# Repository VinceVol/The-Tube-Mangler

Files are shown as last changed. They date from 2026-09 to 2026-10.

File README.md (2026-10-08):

# The-Tube-Mangler
Looking to create a CNC plasma tube notcher &amp; pen plotter to work with 1/2" -> 2" tubing. 

## Active Todos!
- [x] Change the rack mounting to holes rather than slots
- [x] Design for the [rugged limit switches](https://www.amazon.com/Baomain-TZ-3111-Plunger-Momentary-Waterproof/dp/B01HKSDVAK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) used on Jasper the CNC
- [x] Add pulley clearance for axial drive
- [ ] Add encoder mounting location for axial position -- [E4T-1000-197-D-D-M-2 encoder](https://www.digikey.com/en/products/detail/us-digital/E4T-1000-197-D-D-M-2/27558059)
- [ ] Check that all mating holes still line up after several iterations
- [x] Animate the full rotation of the rotary axis to preview collisions
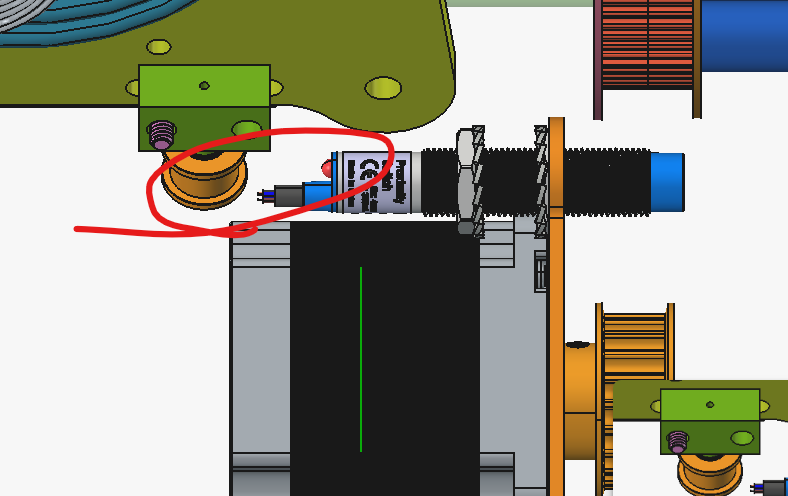
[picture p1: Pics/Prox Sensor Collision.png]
axial tensioning idler collision
	- [x] Move the rotational homing prox sensor to avoid  or find stubby prox sensor
- [ ] Design for cable chains and wire routing
- [ ] Design for physical panel location
- [ ] Draw up schematic using linuxCNC Mesa [7I76EU](https://store.mesanet.com/index.php?route=product/product&product_id=399&search=7I76EU) -- [datasheet](https://www.mesanet.com/pdf/parallel/7i76euman.pdf)

# Path to success
## Step 1 
Mechanical design surrounding the pen plotting/ clamping/ rotating and movement of the tubing

### Axial Roller Drive Math
Outside of literally just trying to fit everything into one small space, we've run into our first issue that requires some brain cells.

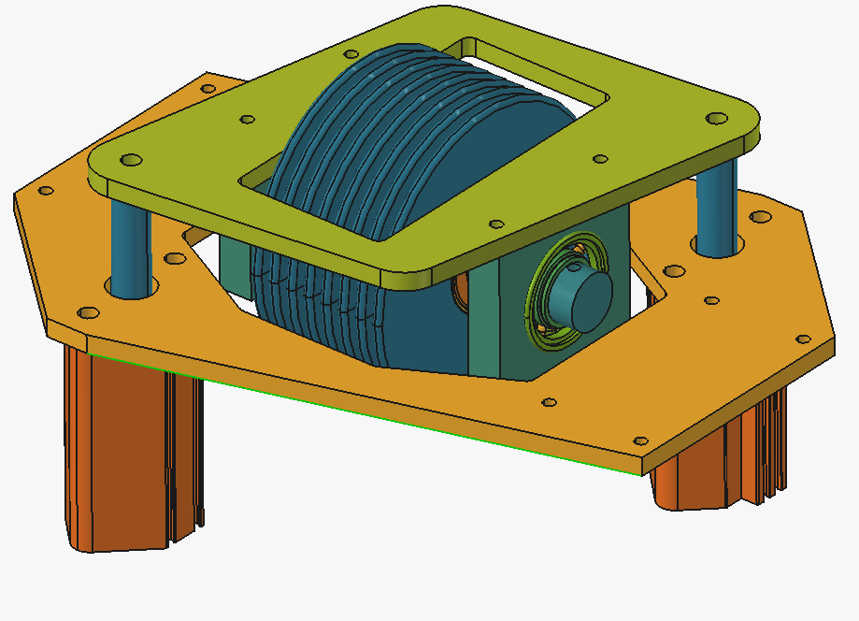
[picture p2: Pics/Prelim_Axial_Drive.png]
**Fig 1.1:** *Axial Drive Preliminary*


The [non slip roller](https://www.mcmaster.com/2494K18/) in the center is has a OD = 4" and the two [air cylinders](https://www.mcmaster.com/62245K166/) have a 1" bore.
At 90 psi we are putting *2 x 90 lbs/in^2 x pi(0.5)^2 in^2 = **141.37** lbs* of force down on this roller. There are two main problems to solve here:

1. Will this "non slip" roller actually not slip at 141 lbs of downforce?
2. Will a stepper motor setup for direct drive stall without some kind of reduction to the non-slip roller?  

Answers:
1. AI says its fine and this feels like more of a "find out" scenario
2. *t = F x r, r = 0.0508m (2in), t = 3 Nm* (big boy stepper), with that we would get *F = 59N = 13lbf*. If we want to chuck up a full 20ft stick of 3"x3" 1/4" thick piece
of tubing at 176lbs, we'd have a hard time doing so with 13lbf. **We need a significant reduction** 

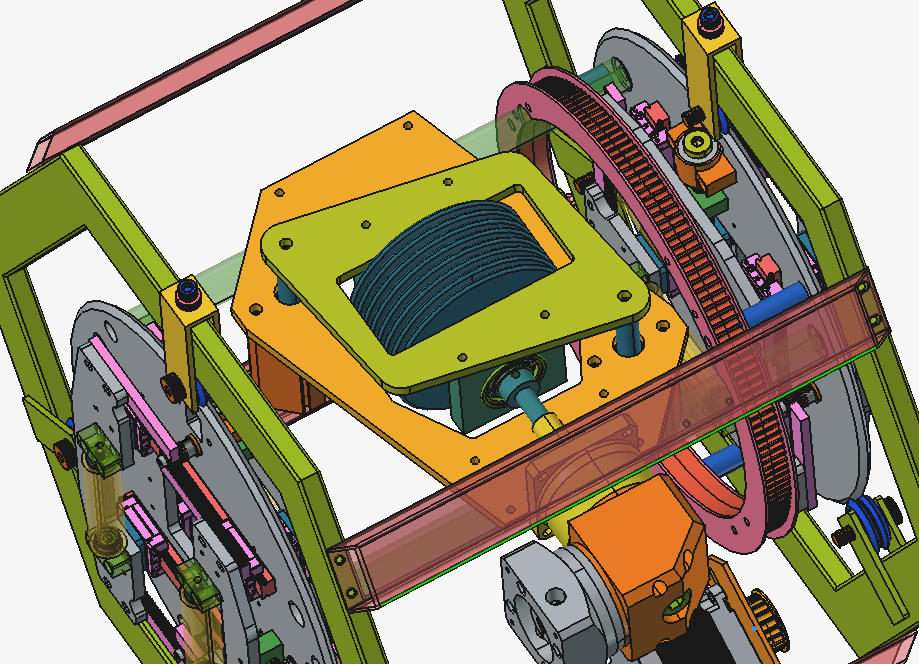
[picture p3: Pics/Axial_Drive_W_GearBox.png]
**Fig 1.2:** *10:1 Gearbox doesnt fit*


Right angle gearbox above was my first thought but it doesnt fit super well. If I downsize to a Nema 17 motor and use a straight 100:1 and using the same sized pulley
to connect the gear box to the roller I think the fit is just about right:

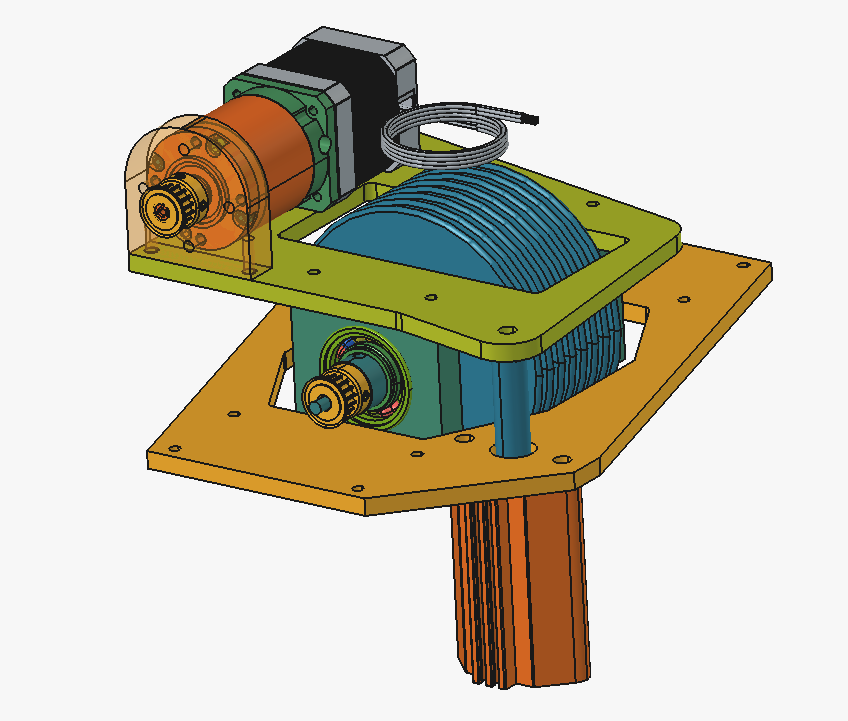
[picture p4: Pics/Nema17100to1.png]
**Fig 1.3:** *100:1 Gearbox w/ Nema 17*


## Step 2 
Addition of plasma cutter

## Step 3
Add the ability --software wise-- to cut square tube

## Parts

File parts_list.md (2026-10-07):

# Parts Lists

## Symmetrical Clamping Chuck

!\[Image of chuck](path)

|**Part Description**|**Part Name**|**Qnty**|**Price**|
|:-:|:-:|:-:|:-:|
|Carriage rep|6709K115|\~|\~|
|Linear Rail|[MGN12C\_150mm](https://ebay.io/m/mMSGYF)|8|20.40|
|Rack Rep|2485N241|\~|\~|
|Pinion Rep|2664N312|\~|\~|
|Pinion Shoulder Bolt|[92981A745](https://www.mcmaster.com/92981A745/)|\~|\~|
|Pinion Shoulder Bolt Bearing|[6659K113](https://www.mcmaster.com/6659K)|\~|\~|
|Pinion Shoulder Bolt Washer|[98689A113](https://www.mcmaster.com/98689A113/)|\~|\~|
|Drive Screw Thrust Bearing|6655K15|\~|\~|
|15 mm GT2/HTD|[7939K15](https://www.mcmaster.com/7939K15/)|\~|\~|

## Chuck Housing

!\[Image of housing](path)

|**Part Description**|**Part Name**|**Qnty**|**Price**|
|:-:|:-:|:-:|:-:|
|Track Bearings|[6321K51](https://ebay.io/m/LhClsj)|\~|\~|
|Track Shoulder Shim Washers|[90214A904](https://a.co/d/0chW9DGh)|\~|\~|
|Bellville Disc Spring|[9712K63](https://www.mcmaster.com/9712K63/)|\~|\~|
|Radial Stepper Motor|[Amazon Hight Torque](https://a.co/d/07xEF6Ci)|\~|\~|
|HTD 5 Belt 890mm|[7939K28](https://www.mcmaster.com/7939K28/)|\~|\~|
|Proximity Sensor|[LJ8A3-2-Z/BY](https://a.co/d/01RUSQrh)|1|22.99|

## Axial Drive

!\[Image of Axial Shit](path)

|**Part Description**|**Part Name**|**Qnty**|**Price**|
|:-:|:-:|:-:|:-:|
|Flanged Bearings|[1.375x0.75x7/8](https://ebay.io/m/fyqjXr)|\~|\~|
|276mm 6mm HTD Belt|[7939K15](https://www.mcmaster.com/7939K15/)|1|26.54|

## Torch \& Pen

!\[Image of that](path)

|**Part Description**|**Part Name**|**Qnty**|**Price**|
|:-:|:-:|:-:|:-:|
|Linear Rail|[MGN12H\_250](https://ebay.io/m/SlpQe4)|2|26.95|
|Linear Rail|[MGN12C\_100](https://ebay.io/m/GM0nUj)|2|19.88|

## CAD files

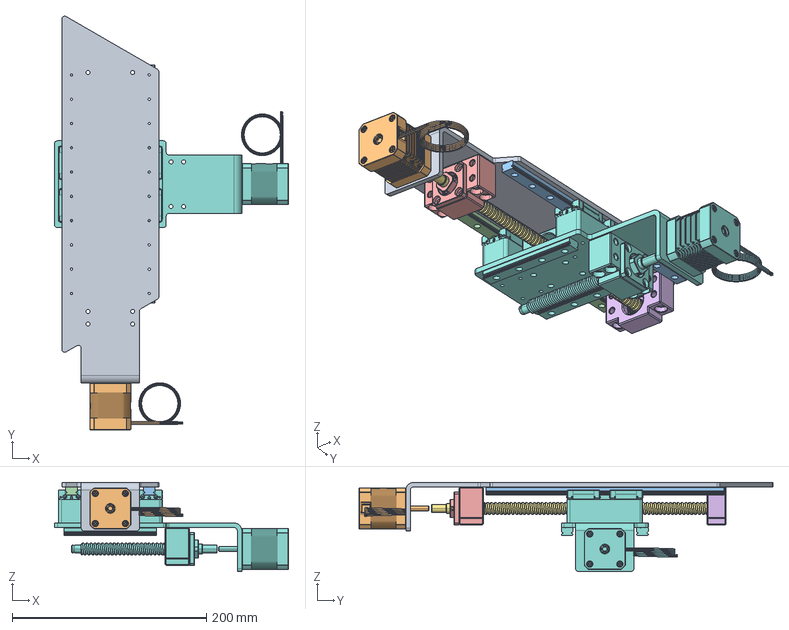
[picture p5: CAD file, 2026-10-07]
CAD/A008_Torch_n_Pen_Main_Assembly.FCStd
240.9 x 426.0 x 91.7 mm
019_Torch_Fixed_Plate001
4798N12_Economy Stepper Motor043
6709K168_270 mm Long x 12 mm Wide Standard Guide Rail for Ball Bearing Carriage003
6709K168_270 mm Long x 12 mm Wide Standard Guide Rail for Ball Bearing Carriage004
BK10_Bearing_Block001
BF011
SFU1204_301
A008_Torch_Z_Plate001
Common 1 - 18 - 6709K168_270 mm Long x 12 mm Wide Standard Guide Rail for Ball Bearing Carriage005 - A008_Torch_Z_Plate002

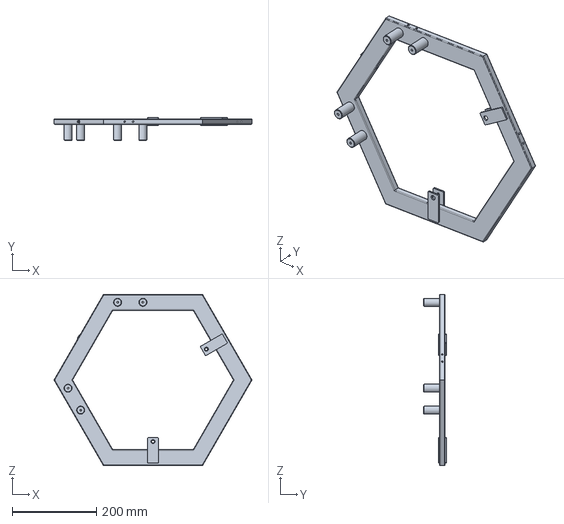
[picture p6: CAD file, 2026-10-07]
CAD/009_Main_Assembly_Triangular_Weldment.FCStd
469.3 x 54.0 x 406.4 mm

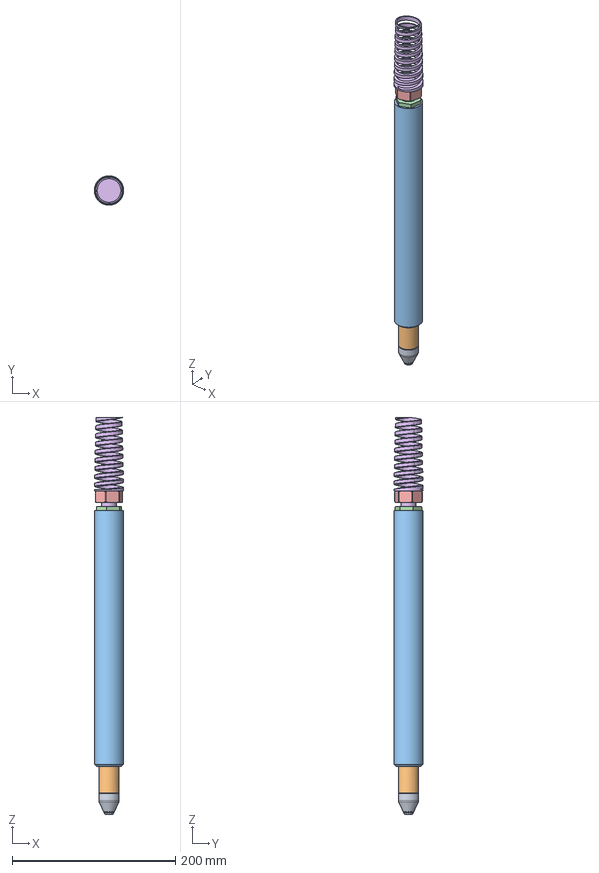
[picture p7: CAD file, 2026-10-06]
Outside Components/Dummy Plasma Torch.FCStd
36.0 x 36.0 x 486.0 mm
Nozzle
Intermediar Nozzle Body
Main Nozzle Body
Lowe Plastic Nut
Upper Plastic Nut
Cable Stress Relief

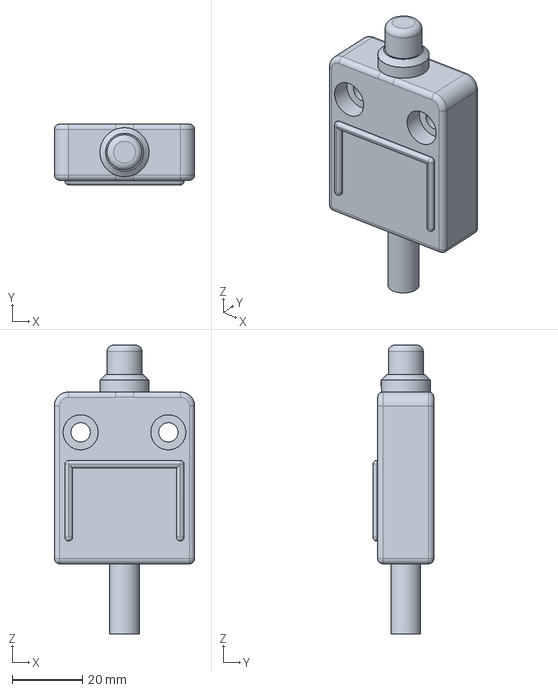
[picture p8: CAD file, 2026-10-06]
Outside Components/BM_3111_BAOMAIN.FCStd
40.0 x 17.3 x 82.4 mm

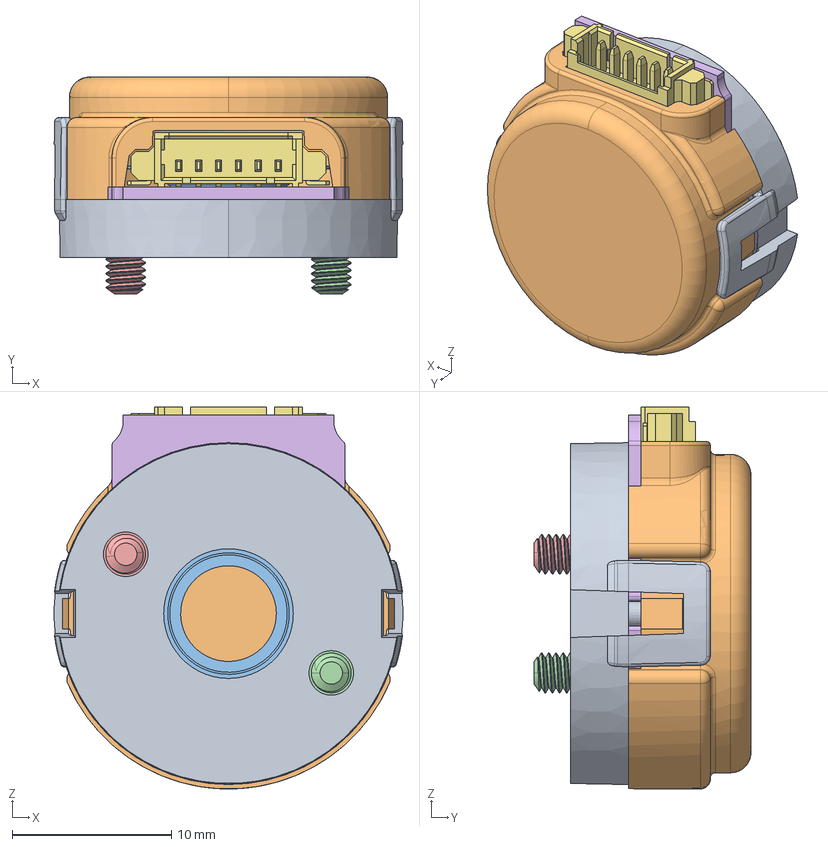
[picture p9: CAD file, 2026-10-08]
Outside Components/E4T-X-236-D-D-M-X007.FCStd
21.9 x 13.6 x 24.0 mm
E4T-X-236-D-D-M-X
E4T-X-236-D-D-M-X001
E4T-X-236-D-D-M-X002
E4T-X-236-D-D-M-X003
E4T-X-236-D-D-M-X004
E4T-X-236-D-D-M-X005
E4T-X-236-D-D-M-X006

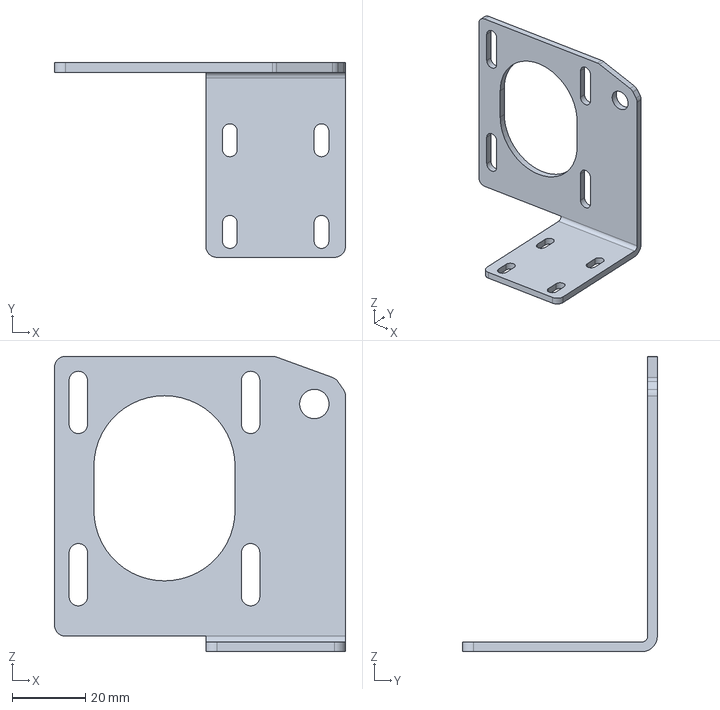
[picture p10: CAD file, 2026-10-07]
CAD/013_Radial_Nema23_Mount.FCStd
79.4 x 53.1 x 80.6 mm

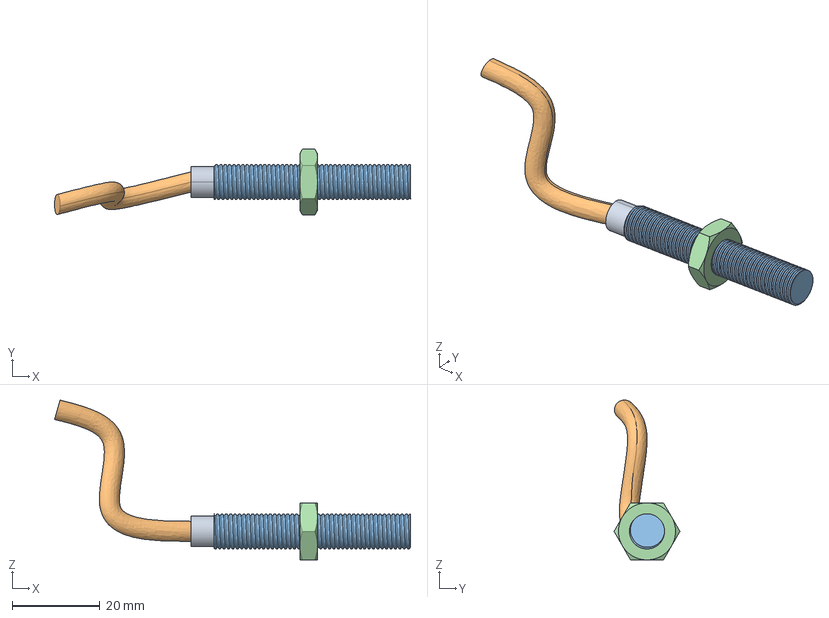
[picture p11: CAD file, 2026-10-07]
Outside Components/LJ8A3-2-Z.FCStd
81.1 x 15.0 x 36.4 mm
Proximity Sensor002
Proximity Sensor003
Hex Nut Jam_AM_B18.2.4.5M - Hex jam nut, M8 x 1.25 --D-N001

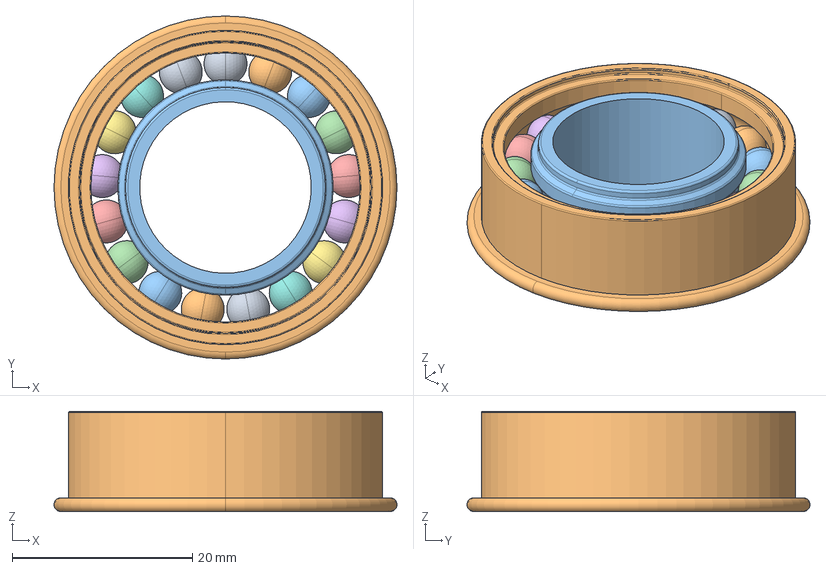
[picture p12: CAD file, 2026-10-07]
Outside Components/Ebay_Axial_Flanged_Bearing_Placeholder.FCStd
38.1 x 38.1 x 11.1 mm
6383K244_Steel Ball Bearing001
6383K244_Steel Ball Bearing002
6383K244_Steel Ball Bearing003
6383K244_Steel Ball Bearing004
6383K244_Steel Ball Bearing005
6383K244_Steel Ball Bearing006
6383K244_Steel Ball Bearing007
6383K244_Steel Ball Bearing008
6383K244_Steel Ball Bearing009
6383K244_Steel Ball Bearing010
6383K244_Steel Ball Bearing011
6383K244_Steel Ball Bearing012
6383K244_Steel Ball Bearing013
6383K244_Steel Ball Bearing014
6383K244_Steel Ball Bearing015
6383K244_Steel Ball Bearing016
6383K244_Steel Ball Bearing017
6383K244_Steel Ball Bearing018

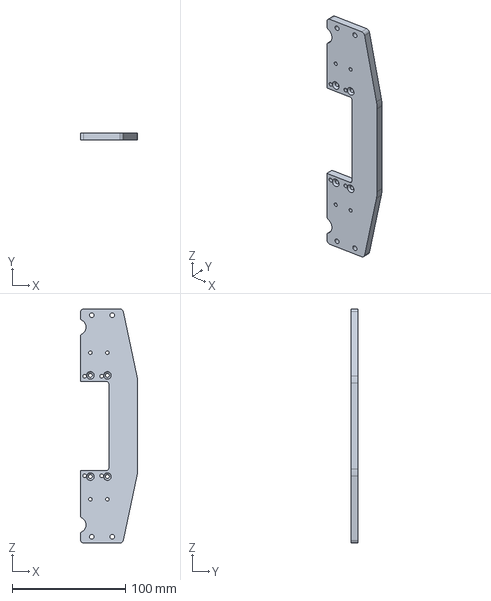
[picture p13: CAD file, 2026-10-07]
CAD/Turntable_clamp_housing.FCStd
50.5 x 6.35 x 206.2 mm

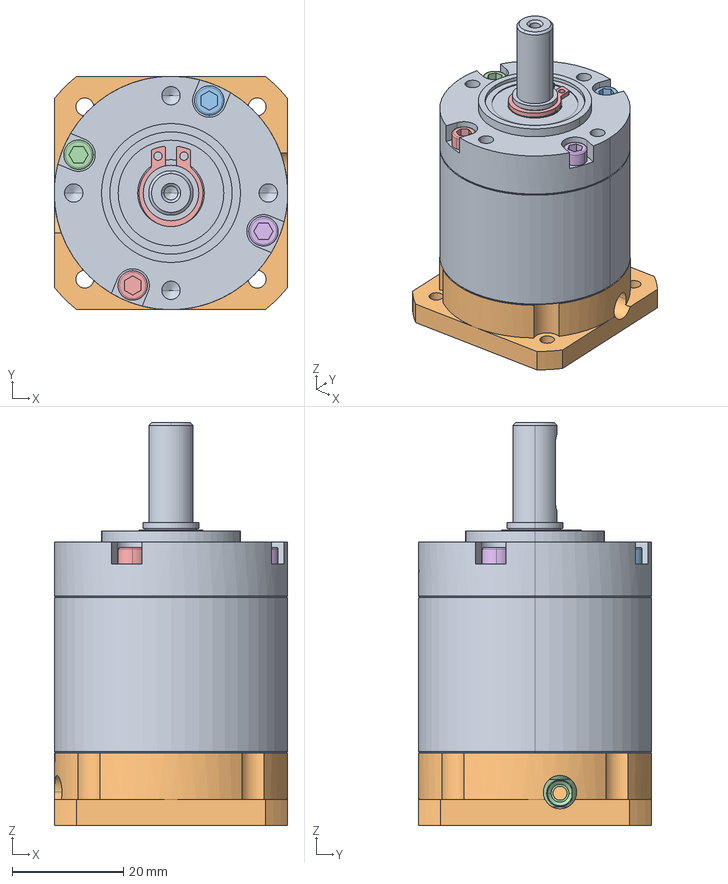
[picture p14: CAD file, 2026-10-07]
Outside Components/MG17-G100.FCStd
42.0 x 42.0 x 72.5 mm
MG17 output-2
42GN Input flange
Input shaft
¦µ10Circlip
M3 hexagon socket screw head
M3 hexagon socket screw head001
M3 hexagon socket screw head002
M3 hexagon socket screw head003
M3 hexagon socket screw head004
M3 hexagon socket screw head005
M3 hexagon socket screw head006
M3 hexagon socket screw head007

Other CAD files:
CAD/Lazy_Clamp_Subassembly_A002.FCStd
CAD/Clamp_Housing_Subassembly_A003.FCStd
CAD/A005_Chuck_Housing_Subassembly.FCStd
CAD/A007_Axial_Drive_Subassembly.FCStd
CAD/Driven_Clamp_Subassembly.FCStd
CAD/A006_Track_and_Weldment_Subassembly.FCStd
CAD/024_Encoder_Housing.FCStd
CAD/A010_Torch_and_Pen_SubA.FCStd
CAD/004_Roller_Block.FCStd
CAD/005_Idler_Roller_3in.FCStd
CAD/006_LeadScrew_Block.FCStd
CAD/007_LeadScrew_Nut.FCStd
CAD/008_Clamp_Housing_Standoff.FCStd
CAD/010_Bellevill_Track_Roller_Mount.FCStd
CAD/011_Weldment_Axial_Bracing.FCStd
CAD/012_Belt_Ring_Standoff.FCStd
CAD/014_Axial_Drive_Plates.FCStd
CAD/015_Axial_Drive_Spindle.FCStd
CAD/016_Nema17_Gearbox_Block.FCStd
CAD/017_Idler_HTD_Block.FCStd
CAD/018_3_4_Standoff_Clamp_Axial_Drive.FCStd
CAD/019_Torch_Fixed_Plate.FCStd
CAD/020_Torch_Moving_Plate.FCStd
CAD/021_Torch_and_Pen_Mount.FCStd
CAD/022_Torch_Clamp_Block.FCStd
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

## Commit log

2026-08-27 Started with the 7738N11 from Mcmaster as a turntable bearing but honestly realizing I think it makes more sense to use external smaller bearings on three points mounted at 45 degrees to lock the rot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
    At this point trying to decide on whether to use linear rails or some kind of T block or dovetail slide for these clamps
    Another piece up for debate is whether to have slides on two sides of the 'turntable' and whether to connect those slides via a bracket through the center
    [7738M11_Turntable_Bearing.FCStd, 7738N11_Low-Profile Turntable Bearing.STEP, TubeMangler_Main_Assembly.FCStd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]
2026-08-28 -Started working through the master sketch driving the self centering chuck mechanism, based on https://www.youtube.com/watch?v=IYpCCXOFvMg -Listed the part numbers from mcmaster that I'm using as a 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
    [Turntable_clamp_housing.FCStd]
2026-08-28 Working through component choice some more, mostly dialing in how I want the pinion gear to rotate easily -- landing on a shouldered oiled sleeve bearing that I can press into the plate and use a sho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
    [2664N312_Metal Gear - 20 Degree Pressure Angle.FCStd, 6659K113_Oil-Embedded 841 Bronze Flanged Sleeve Bearing.FCStd, 6709K115_Ball Bearing Carriage.FCStd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]
2026-08-31 Working through the driven clamp on the rotatating clamp subassembly. Right now looking at slotting the holes that hold the rack to give it some adjustment to get on center. Also looking to use a bea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
    [002_Carriage_n_Raiul_Assembly.FCStd, 003_Pinion_Subassembly.FCStd, 2664N312_Metal Gear - 20 Degree Pressure Angle.FCStd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]
2026-09-02 Needed to switch to the stable release of freecad because the assembly workbench is absolutely nuked in the nightly builds.
    Building up the driven clamp assembly and sourcing some components still
    Wanting to change the roller to be tube based with bearings that press into the tube od (Keep it simple) maybe with some shoulderless shoulder bolts as the shitty axle
    [6153K69_Corrosion-Resistant 440C Stainless Steel Ball Bearing.FCStd, 90318A770_Low_Profile_PBB_Shoulder_Bolt.FCStd, 90318A780_Low_Profile_PBB_Shoulder_Bolt.FCS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]
2026-09-02 -Consistently fighting the new freecad assembly workbench, everything breaks when I make small changes. -May need to switch to assembly 4 and start whipping up the good old LCS to have working joints
    [004_Roller_Block.FCStd, 57155K321_075OD316ID_Flanged roller ball bearing.FCStd, 90318A780_Low_Profile_PBB_Shoulder_Bolt.FCStd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]
2026-09-02 Using Assembly 4 now and rebuilding a lot of the stuff that kept breaking. There may be some corruption in the original turntable file that could be messing with the assembly as well. fingers crossed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
    About to design for a leadscrew on the driven clamp and then going to start drawing up the non_driven clamp
    [004_Roller_Block.FCStd, 005_Idler_Roller_3in.FCStd, 2485N241_Metal Gear Rack - 20 Degree Pressure Angle001_Modified.FCStd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]
2026-09-03 started working on the lazy clamp (non driven) I think I need to lose the push back bearings as it'd be hard to fit one on the lazy side
    [004_Roller_Block.FCStd, 6709K115_Ball Bearing Carriage.FCStd, Driven_Clamp_Subassembly.FCStd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]
2026-09-03 -Some of the naming conventions I tried to start with got screwed up but will try and fix with time -Mostly done with the driven and lazy clamp and assembling with the clamp base now to figure out wh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
    [004_Roller_Block.FCStd, 005_Idler_Roller_3in.FCStd, 2485N241_Metal Gear Rack - 20 Degree Pressure Angle001_Modified.FCStd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]
2026-09-04 -Thank goodness for git because somewhere through using assembly 4 my main lazy and driven clamp got deleted and nuked my subassemblies -Realizing now that I have interference potentially between the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
    [003_Pinion_Subassembly.FCStd, 004_Roller_Block.FCStd, 005_Idler_Roller_3in.FCStd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]
2026-09-05 Created the open and closed configurations on the clamp Had to add some clearance for the shoulder bolt holding the pinion Need to dial in the spacing between the rack and pinion now
    [004_Roller_Block.FCStd, 005_Idler_Roller_3in.FCStd, 2485N241_Metal Gear Rack - 20 Degree Pressure Angle001_Modified.FCStd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]
2026-09-05 Moved the racks closer together but maybe broke some shit in the doing The turntable file that was created in freecad 1.2 definitely has some hidden bug that makes it self nuke depending on what I do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
    [004_Roller_Block.FCStd, 005_Idler_Roller_3in.FCStd, 2485N241_Metal Gear Rack - 20 Degree Pressure Angle001_Modified.FCStd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]
2026-09-05 Fixed rack and pinion spacing
    [Clamp_Housing_Subassembly_A003.FCStd, Lazy_Clamp_Subassembly_A002.FCStd, Turntable_clamp_housing.FCStd]
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2026-09-07 Finished assembling the turntable with the components available and now just debating on the best way to incorporate a leadscrew in the 12.8mm available
    [004_Roller_Block.FCStd, 005_Idler_Roller_3in.FCStd, 006_LeadScrew_Block.FCStd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]
2026-09-08 Working through the leadscrew block and trying to make it work with thrust bearings, may be a lost cause and should potnetially stick to bushings. If I end up going with thrust bearings I think I'll 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
    [006_LeadScrew_Block.FCStd, Clamp_Housing_Subassembly_A003.FCStd, Lazy_Clamp_Subassembly_A002.FCStd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]
2026-09-09 Having issues with commit but basically implemented leadscrew and had to modify some stuff to make it happen including turntable OD
    [004_Roller_Block.FCStd, 005_Idler_Roller_3in.FCStd, 006_LeadScrew_Block.FCStd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]
2026-09-09 About to assemble the chuck housing subassembly, saving before it breaks, added holes for standoffs and drew 12 in long 3/4 in standoffs
    [004_Roller_Block.FCStd, 005_Idler_Roller_3in.FCStd, 006_LeadScrew_Block.FCStd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]
2026-09-09 Started the chuck housing assembly and chamfered the turntable plates to allow for the track/ bearing v guide rollers Internally debating on the best way to add the supporting structure and thinking 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
    [004_Roller_Block.FCStd, 005_Idler_Roller_3in.FCStd, 006_LeadScrew_Block.FCStd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]
2026-09-10 Starting to work through the weldment and looking like 1.5 x.5 tube with the v bearings between tubing thickness Need to start working through way of adding preload and proabably allowing for some gi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
    [009_Main_Assembly_Triangular_Weldment.FCStd]
2026-09-10 Made some progress on the weldment holding the turntables. One of the three v bearings can't move axially or radially, the next cant move radially but can slide on a shoulder axially and the last can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
    [004_Roller_Block.FCStd, 005_Idler_Roller_3in.FCStd, 006_LeadScrew_Block.FCStd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]
2026-09-10 Theres something broken about the sketch driving the weldment we've been working on, none of the dimensions are being shown. Need to add clearance for the track bearings tho or grow the weldment size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
    [004_Roller_Block.FCStd, 005_Idler_Roller_3in.FCStd, 006_LeadScrew_Block.FCStd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]
2026-09-10 realized the geometry constraints were for the weldment were just hidden so fixed the clearance issue with the track rollers
    [009_Main_Assembly_Triangular_Weldment.FCStd, A005_Chuck_Housing_Subassembly.FCStd, A006_Track_and_Weldment_Subassembly.FCStd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]
2026-09-11 Added the bellville preload mechanism for the weldments Now need to design for cross members and how I'm actually going to mount servos to drive stuff in all directions
    [004_Roller_Block.FCStd, 005_Idler_Roller_3in.FCStd, 006_LeadScrew_Block.FCStd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]
2026-09-11 Added the cross bracing and shortened standoffs to get center to center width of 12in between clamps
    [004_Roller_Block.FCStd, 005_Idler_Roller_3in.FCStd, 006_LeadScrew_Block.FCStd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]
2026-09-11 Mostly spent some time figuring out how we wanted to spin this thing, looking like bolting on 8 pieces around one of the plates thatwill create a step for a regular belt and pully to interface with, 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
    [004_Roller_Block.FCStd, 005_Idler_Roller_3in.FCStd, 006_LeadScrew_Block.FCStd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]
2026-09-11 Looking like we need offsets to allow for the leadscrew to be tightened otherwise the belt ring gets in the way
    [004_Roller_Block.FCStd, 005_Idler_Roller_3in.FCStd, 006_LeadScrew_Block.FCStd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]
2026-09-12 Finding weird bug where parts that cause assembly 4 to crash will self nuke, commiting to try and save my redrawn inner belt ring. Still working through the details of shifting things around to get t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
    [004_Roller_Block.FCStd, 005_Idler_Roller_3in.FCStd, 006_LeadScrew_Block.FCStd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]
2026-09-12 Have redrawn the inner and outer belt race alongside some 0.5in standoffs, saving before assembly as freecad continues to randomly delete parts
    [004_Roller_Block.FCStd, 005_Idler_Roller_3in.FCStd, 006_LeadScrew_Block.FCStd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]
2026-09-12 Successfully incorporated the belt drive ring. now need to work on motor mount and tensioning
    [004_Roller_Block.FCStd, 005_Idler_Roller_3in.FCStd, 006_LeadScrew_Block.FCStd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]
2026-09-12 Got the stepper motor for the radial movement mounted -- will still need to determine the proper belt size
    [004_Roller_Block.FCStd, 005_Idler_Roller_3in.FCStd, 006_LeadScrew_Block.FCStd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]
2026-09-12 Drawing up the 5M HTD pulley geo into the large pulley we are making for the radial movement. worried about a crash
    [A005_Chuck_Housing_Subassembly.FCStd, Clamp_Housing_Subassembly_A003.FCStd, Driven_Clamp_Subassembly.FCStd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]
2026-09-12 We successfully added the teeth but need to move the holes inbound a bit further or add a few more teeth in order to give ourselved a bit more breathing room between the valley of the teeth and the h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
    [009_Main_Assembly_Triangular_Weldment.FCStd, 010_Bellevill_Track_Roller_Mount.FCStd, A005_Chuck_Housing_Subassembly.FCStd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]
2026-09-12 Resized the axial driven pulley to help with the last commit. Need to rework LCS mounts so everything goes together
    [004_Roller_Block.FCStd, 005_Idler_Roller_3in.FCStd, 006_LeadScrew_Block.FCStd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]
2026-09-12 Fixed up the assembly, last thing needed for the radial drive portion is finding the right pulley and identifying the right belt length
    [004_Roller_Block.FCStd, 005_Idler_Roller_3in.FCStd, 006_LeadScrew_Block.FCStd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]
2026-09-13 -Pulley for radial movement got dimensional adjustments for teeth geo to match the mcmaster pulley. -Shifted the nema23 motor mount around such that the tight position pulls a 890mm belt tought (whic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
    [004_Roller_Block.FCStd, 005_Idler_Roller_3in.FCStd, 006_LeadScrew_Block.FCStd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]
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2026-09-16 Slow churn on working through making the axial drive compatable with a 276mm long 6mm wide belt. Basically need an idler for this to work. The idler positioning needs some more adjustment and I need 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
    [005_Idler_Roller_3in.FCStd, 006_LeadScrew_Block.FCStd, 007_LeadScrew_Nut.FCStd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]
2026-09-17 Fixed the idler pulley positioning for a tought 276mm belt. Need to fix the slot size to use carriage bolts and need to adjust the plate clearance for the idler now that its so far out
    [002_Carriage_n_Raiul_Assembly.FCStd, 009_Main_Assembly_Triangular_Weldment.FCStd, 010_Bellevill_Track_Roller_Mount.FCStd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]
2026-09-17 Added the standoff clamping bocks that bolt to the axial drive plates. Need to fix references between the axial drive plates as I've changed enough to where my binders are broken now
    [009_Main_Assembly_Triangular_Weldment.FCStd, 010_Bellevill_Track_Roller_Mount.FCStd, 011_Weldment_Axial_Bracing.FCStd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]
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2026-09-24 Started getting a bit more done regarding the parts that hold and move the torch around. Trying to stick w 12mm rails, Nema 17 motors and initially had SFU16 ball screws but now going to SFU1204 to k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
    [019_Torch_Fixed_Plate.FCStd, 020_Torch_Moving_Plate.FCStd, 4798N12_Economy Stepper Motor042.FCStd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]
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2026-10-03 Refactored the nema 23 radial motor mount to take a prox sensor, need to fix A005 for the large pulley placement but difficult to do on laptop (lag)
    [009_Main_Assembly_Triangular_Weldment.FCStd, 010_Bellevill_Track_Roller_Mount.FCStd, 013_Radial_Nema23_Mount.FCStd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]
2026-10-03 Fixed the roller block positioning due to broken references on the driven and lazy clamp and changed the slots to hole for the racks (finally)
    [004_Roller_Block.FCStd, A005_Chuck_Housing_Subassembly.FCStd, Turntable_clamp_housing.FCStd]
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2026-10-06 Ended up reworking A005 because I'm to lazy to rebuild the full assembly in A011 so I removed it
    [005_Idler_Roller_3in.FCStd, 006_LeadScrew_Block.FCStd, 007_LeadScrew_Nut.FCStd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]
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2026-10-07 Added clearance for the axial drive belt.
    [014_Axial_Drive_Plates.FCStd, 015_Axial_Drive_Spindle.FCStd, 016_Nema17_Gearbox_Block.FCStd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]
2026-10-07 Found a 8mm prox sensor that doesn't cause collision issues with the axial drive plates
    [009_Main_Assembly_Triangular_Weldment.FCStd, 010_Bellevill_Track_Roller_Mount.FCStd, 013_Radial_Nema23_Mount.FCStd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]
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2026-10-12 Realizing we need to refactor some of the clamp idler designs to better accomodate the encoder and the better constrain those rollers to prevent a ton of rubbing
2026-10-12 Fixed the roller geometry on the driven and lazy clamp to work with cheaper bearings and to be better constraint.
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
